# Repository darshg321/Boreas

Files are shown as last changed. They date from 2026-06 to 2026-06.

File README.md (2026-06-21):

# Boreas

a flight controller for a rocket.

made this project to both learn how to make flight controllers in general for my drone. making it i got some more practice in routing pcbs and how to read datasheets!
the plan for this board is to be used in a rocket im going to make, where hopefully with the gyro and motor pins i can get it to 1km altitude or higher. little ambitious for my first rocket project but i tihnk it should be fine! for its kind of a big pcb so it'll be hard to fit on the rocket but itll work fine i think. also the sd card will be useful to gain cool telemetry, and i plan to use it to generate interesting graphs that can tell me how to improve the rocket further.

it uses an STM32F7 as an mcu, connected to an imu, barometer, and magnometer. it also has 3 leds, two buttons, a buzzer, and 3 servo motor pins. it can also charge lipo batteries through usb-c! lastly it has an sd card reader for data display!

## Poster (Zine)
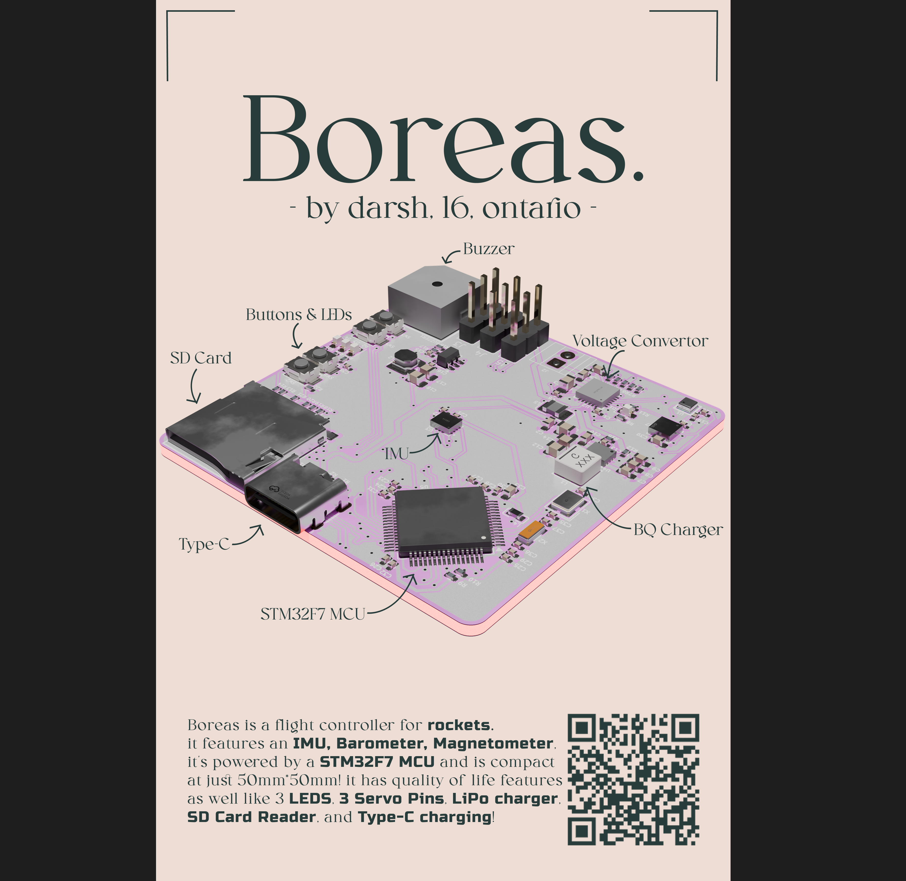
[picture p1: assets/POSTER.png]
poster


## Render
render

## Schematic
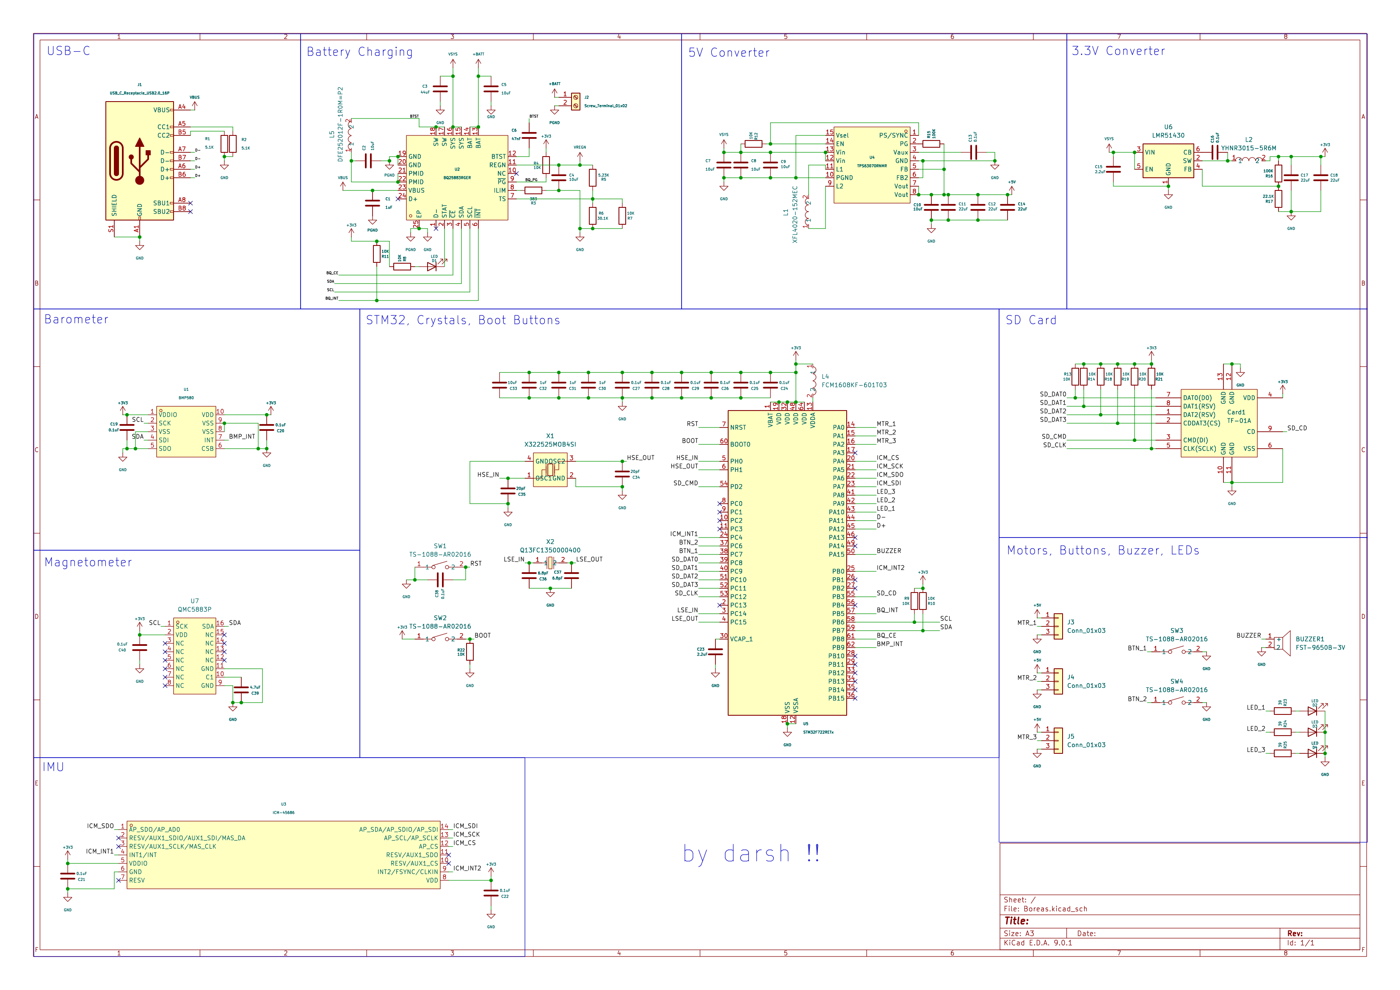
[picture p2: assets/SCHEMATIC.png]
schem


## PCB
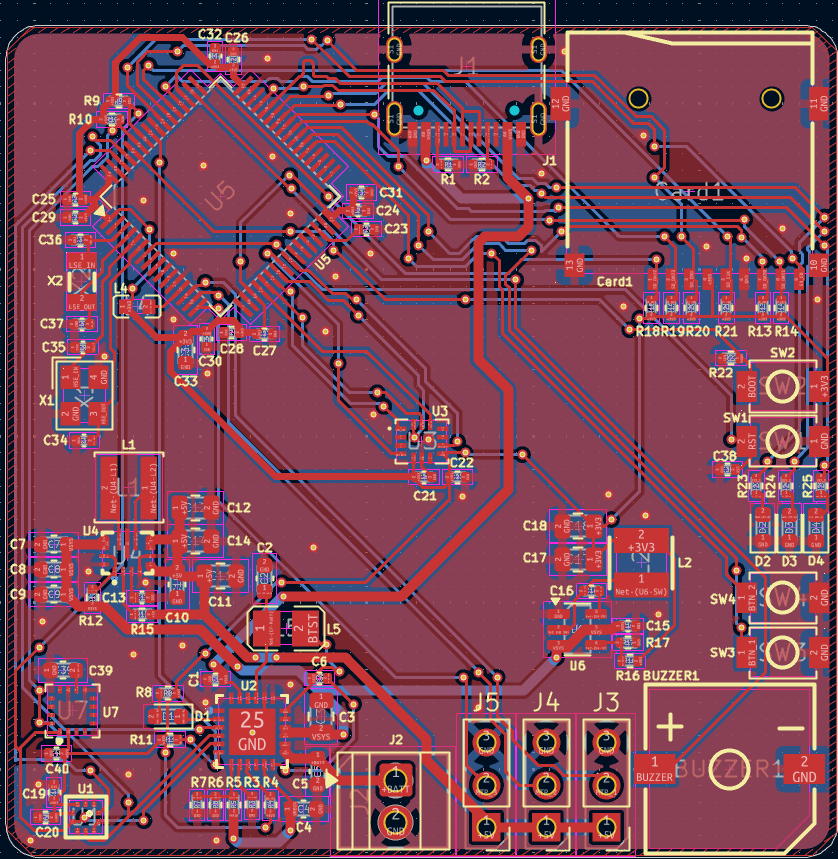
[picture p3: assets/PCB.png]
pcb


## To use

1. plug assembled PCB into computer
2. run ```make flash``` in firmware path after pressing boot and reset buttons to enter flashing mode on the STM32

## BOM

|Item |Price (USD)|
|---|---|
|PCB |2 |
|PCBA |198.65 |
|Shipping|26.51 |
| | |
|Total |227.16 |

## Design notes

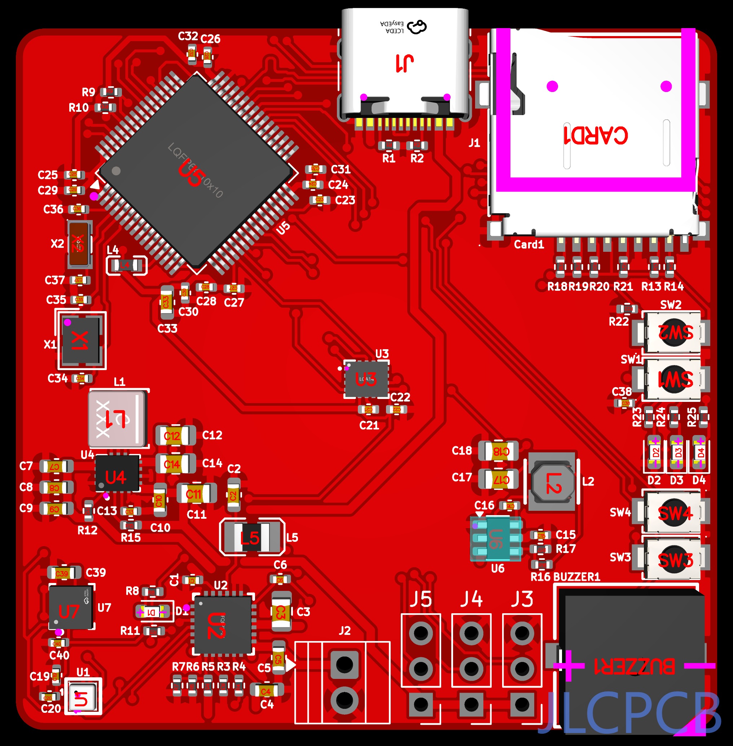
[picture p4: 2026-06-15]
assets/PCB_JLC.png

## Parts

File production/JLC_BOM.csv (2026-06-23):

JLCPCB BOM Tool - BOM Matching
BOM name：production_bom-JLCPCB Assembly Order.xlsx |  |  | Download Time：2026-06-12 11:30:08 |  |  |  | * Our matching results are updated in real-time, but stock and prices may change. If it's been over 24 hours, please re-match before placing your order.
PCB Assembled Qty：5 |  |  | Est. Total Price：69.0311
Your BOM |  |  |  |  | Matched Parts |  |  |  |  |  |  | Order Information
Top Designator | Bottom Designator | Comment | Footprint | JLCPCB Part # | Matches | Part # | Manufacturer | Footprint | Description | Category | Warning | JLCPCB Part # | Product link | Lib Type | Qty | Source | Total Price ($)
BUZZER1 |  | FST-9650B-3V | BUZ-SMD_L9.6-W9.6-LS10.0-R |  | Select by System | FUET-9650B-3V | FUET | SMD,9.6x9.6mm | -20℃~+80℃ 2V~5V 30mA 3V 3kHz 5.5mm 85dB 9.6mm 9.6mm Active Buzzer (Built-in Driving Circuit) Electromagnetic SMD,9.6x9.6mm Buzzers ROHS | Buzzers |  | C391032 | https://jlcpcb.com/partdetail/FUET-FUET_9650B3V/C391032 | Extended | 2 | 2 JLCPCB | 1.1802
C1,C30,C31,C32 |  | 1uF | 402 |  | Select by System | CL05A105KA5NQNC | Samsung Electro-Mechanics | 402 | 1uF 25V X5R ±10% 0402 Multilayer Ceramic Capacitors MLCC - SMD/SMT ROHS | Multilayer Ceramic Capacitors MLCC - SMD/SMT |  | C52923 | https://jlcpcb.com/partdetail/53938-CL05A105KA5NQNC/C52923 | Basic | 20 | 20 JLCPCB | 0.138
C3 |  | 44uF | 805 |  | Select by Customer | CL21A476MQYNNNE | Samsung Electro-Mechanics | 805 | 47uF 6.3V X5R ±20% 0805 Multilayer Ceramic Capacitors MLCC - SMD/SMT ROHS | Multilayer Ceramic Capacitors MLCC - SMD/SMT |  | C16780 | https://jlcpcb.com/partdetail/17464-CL21A476MQYNNNE/C16780 | Basic | 8 | 8 JLCPCB | 1.0848
C6 |  | 47nF | 402 |  | Select by Customer | 0402B473K500NT | FH (Guangdong Fenghua Advanced Tech) | 402 | 47nF 50V X7R ±10% 0402 Multilayer Ceramic Capacitors MLCC - SMD/SMT ROHS | Multilayer Ceramic Capacitors MLCC - SMD/SMT |  | C82219 | https://jlcpcb.com/partdetail/83376-0402B473K500NT/C82219 | Extended | 20 | 20 JLCPCB | 0.068
C10,C2,C33,C4,C5,C7,C8,C9 |  | 10uF | 603 |  | Select by System | CL10A106KP8NNNC | Samsung Electro-Mechanics | 603 | 10V 10uF X5R ±10% 0603 Multilayer Ceramic Capacitors MLCC - SMD/SMT ROHS | Multilayer Ceramic Capacitors MLCC - SMD/SMT |  | C19702 | https://jlcpcb.com/partdetail/20411-CL10A106KP8NNNC/C19702 | Basic | 26 | 26 JLCPCB | 0.4498
C11,C12,C14,C17,C18 |  | 22uF | 805 |  | Select by System | CL21A226MAQNNNE | Samsung Electro-Mechanics | 805 | 22uF 25V X5R ±20% 0805 Multilayer Ceramic Capacitors MLCC - SMD/SMT ROHS | Multilayer Ceramic Capacitors MLCC - SMD/SMT |  | C45783 | https://jlcpcb.com/partdetail/46786-CL21A226MAQNNNE/C45783 | Basic | 18 | 18 JLCPCB | 1.7082
C13,C16,C19,C20,C21,C22,C24,C25,C26,C27,C28,C29,C38,C40 |  | 0.1uF | 402 |  | Unconfirmed | CL05B104KO5NNNC | Samsung Electro-Mechanics | 402 | 100nF 16V X7R ±10% 0402 Multilayer Ceramic Capacitors MLCC - SMD/SMT ROHS | Multilayer Ceramic Capacitors MLCC - SMD/SMT | 1.The comment (CL05B104KO5NNNC) of this part does not match the one (0.1uF) provided in your BOM. Please confirm; | C1525 | https://jlcpcb.com/partdetail/1877-CL05B104KO5NNNC/C1525 | Basic | 38 | 38 JLCPCB | 0.0874
C15,C23 |  | 2.2uF | 402 |  | Select by System | CL05A225MQ5NSNC | Samsung Electro-Mechanics | 402 | 2.2uF 6.3V X5R ±20% 0402 Multilayer Ceramic Capacitors MLCC - SMD/SMT ROHS | Multilayer Ceramic Capacitors MLCC - SMD/SMT |  | C12530 | https://jlcpcb.com/partdetail/13164-CL05A225MQ5NSNC/C12530 | Basic | 20 | 20 JLCPCB | 0.154
C34,C35 |  | 20pF | 402 |  | Select by System | 0402CG200J500NT | FH (Guangdong Fenghua Advanced Tech) | 402 | 20pF 50V C0G ±5% 0402 Multilayer Ceramic Capacitors MLCC - SMD/SMT ROHS | Multilayer Ceramic Capacitors MLCC - SMD/SMT |  | C1554 | https://jlcpcb.com/partdetail/1906-0402CG200J500NT/C1554 | Basic | 20 | 20 JLCPCB | 0.042
C36,C37 |  | 6.8pF | 402 |  | Select by Customer | 0402CG6R8C500NT | FH (Guangdong Fenghua Advanced Tech) | 402 | 50V 6.8pF C0G 0402 Multilayer Ceramic Capacitors MLCC - SMD/SMT ROHS | Multilayer Ceramic Capacitors MLCC - SMD/SMT |  | C1576 | https://jlcpcb.com/partdetail/1928-0402CG6R8C500NT/C1576 | Extended | 20 | 20 JLCPCB | 0.048
C39 |  | 4.7uF | 603 |  | Select by System | CL10A475KO8NNNC | Samsung Electro-Mechanics | 603 | 16V 4.7uF X5R ±10% 0603 Multilayer Ceramic Capacitors MLCC - SMD/SMT ROHS | Multilayer Ceramic Capacitors MLCC - SMD/SMT |  | C19666 | https://jlcpcb.com/partdetail/20375-CL10A475KO8NNNC/C19666 | Basic | 20 | 20 JLCPCB | 0.368
CARD1 |  | TF-01A | TF-SMD_TF-01A |  | Select by System | TF-01A | Korean Hroparts Elec | SMD | 1.85mm Connector and Ejector MicroSD Card (TF Card) Push-Push With Locating Pins SMD SD Card / Memory Card Connector ROHS | SD Card / Memory Card Connector |  | C91145 | https://jlcpcb.com/partdetail/Korean_HropartsElec-TF01A/C91145 | Extended | 2 | 2 JLCPCB | 0.3806
D1,D2,D3,D4 |  | LED | 603 |  | Select by Customer | KT-0603G | Hubei KENTO Elec | 603 | -40℃~+85℃ 1.6mm x 0.8mm square LED 100mW 120° 3.1V 430mcd 513nm~528nm 525nm 5mA Discrete Diode Emerald Green Water Clear 0603 LED Indication - Discrete ROHS | LED Indication - Discrete | 1.The comment (KT-0603G) of this part does not match the one (LED) provided in your BOM. Please confirm; | C12624 | https://jlcpcb.com/partdetail/Hubei_KENTOElec-KT0603G/C12624 | Extended | 20 | 20 JLCPCB | 0.242
J1 |  | USB_C_Receptacle_USB2.0_16P | USB_C_Receptacle_HRO_TYPE-C-31-M-12 |  | Select by Customer | TYPE-C-31-M-12 | Korean Hroparts Elec | SMD | -30℃~+80℃ 1 10,000 cycles 16P 20V 5A 7.35mm Female Surface Mount, Right Angle Type-C SMD USB Connectors ROHS | USB Connectors |  | C165948 | https://jlcpcb.com/partdetail/Korean_HropartsElec-TYPE_C_31_M12/C165948 | Extended | 2 | 2 JLCPCB | 0.3684
L1 |  | XFL4020-152MEC | IND-SMD_L4.0-W4.0-A |  | Select by System | XFL4020-152MEC | Coilcraft | SMD,4x4mm | 1.5uH 14.4mΩ 4.6A 9.1A Magnetic Shielded Inductor ±20% SMD,4x4mm Power Inductors ROHS | Power Inductors |  | C3033018 | https://jlcpcb.com/partdetail/Coilcraft-XFL4020152MEC/C3033018 | Extended | 2 | 2 JLCPCB | 2.7506
L2 |  | YHNR3015-5R6M | IND-SMD_L3.0-W3.0 |  | Select by System | YHNR3015-5R6M | YJYCOIN | SMD,3x3mm | 2.2A 250mΩ 5.6uH Magnetic Shielded Inductor ±20% SMD,3x3mm Power Inductors ROHS |  |  | C18236327 | https://jlcpcb.com/partdetail/YJYCOIN-YHNR30155R6M/C18236327 | Extended | 15 | 15 JLCPCB | 1.1235
L4 |  | FCM1608KF-601T03 | L0603 |  | Select by Customer | BLM18EG601SN1D | Murata Electronics | 603 | -55℃~+125℃ 1 350mΩ 500mA 600Ω@100MHz ±25% 0603 Ferrite Beads ROHS | Ferrite Beads |  | C20345 | https://jlcpcb.com/partdetail/MurataElectronics-BLM18EG601SN1D/C20345 | Extended | 10 | 10 JLCPCB | 0.81
L5 |  | DFE252012F-1R0M=P2 | L2520 |  | Select by System | DFE252012F-1R0M=P2 | Murata Electronics | 1008 | 1uH 3.3A 4.7A 40mΩ ±20% 1008 Power Inductors ROHS | Power Inductors |  | C435392 | https://jlcpcb.com/partdetail/MurataElectronics-DFE252012F_1R0MP2/C435392 | Extended | 5 | 5 JLCPCB | 0.909
R1,R2 |  | 5.1K | 402 |  | Unconfirmed | 0402WGF5101TCE | UNI-ROYAL(Uniroyal Elec) | 402 | -55℃~+155℃ 5.1kΩ 50V 62.5mW Thick Film Resistor ±1% ±100ppm/℃ 0402 Chip Resistor - Surface Mount ROHS | Chip Resistor - Surface Mount | 1.The comment (0402WGF5101TCE) of this part does not match the one (5.1K) provided in your BOM. Please confirm; | C25905 | https://jlcpcb.com/partdetail/26648-0402WGF5101TCE/C25905 | Basic | 20 | 20 JLCPCB | 0.018
R3 |  | 383 | 402 |  | Select by Customer | RTT023830FTH | RALEC | 402 | -55℃~+155℃ 383Ω 50V 62.5mW Thick Film Resistor ±1% ±100ppm/℃ 0402 Chip Resistor - Surface Mount ROHS | Chip Resistor - Surface Mount | 1.The comment (RTT023830FTH) of this part does not match the one (383) provided in your BOM. Please confirm; | C112940 | https://jlcpcb.com/partdetail/RALEC-RTT023830FTH/C112940 | Extended | 20 | 20 JLCPCB | 0.012
R5 |  | 5.23K | 402 |  | Unconfirmed | FRC0402F5231TS | FOJAN | 402 | -55℃~+155℃ 5.23kΩ 50V 62.5mW Thick Film Resistor ±1% ±100ppm/℃ 0402 Chip Resistor - Surface Mount ROHS | Chip Resistor - Surface Mount | 1.The comment (FRC0402F5231TS) of this part does not match the one (5.23K) provided in your BOM. Please confirm; | C2933105 | https://jlcpcb.com/partdetail/FOJAN-FRC0402F5231TS/C2933105 | Extended | 20 | 20 JLCPCB | 0.018
R6 |  | 30.1K | 402 |  | Unconfirmed | 0402WGF3012TCE | UNI-ROYAL(Uniroyal Elec) | 402 | -55℃~+155℃ 30.1kΩ 50V 62.5mW Thick Film Resistor ±1% ±100ppm/℃ 0402 Chip Resistor - Surface Mount ROHS | Chip Resistor - Surface Mount | 1.The comment (0402WGF3012TCE) of this part does not match the one (30.1K) provided in your BOM. Please confirm; | C29402 | https://jlcpcb.com/partdetail/30156-0402WGF3012TCE/C29402 | Extended | 20 | 20 JLCPCB | 0.02
R10,R11,R12,R13,R14,R18,R19,R20,R21,R22,R4,R7,R8,R9 |  | 10K | 402 |  | Unconfirmed | 0402WGF1002TCE | UNI-ROYAL(Uniroyal Elec) | 402 | -55℃~+155℃ 10kΩ 50V 62.5mW Thick Film Resistor ±1% ±100ppm/℃ 0402 Chip Resistor - Surface Mount ROHS | Chip Resistor - Surface Mount | 1.The comment (0402WGF1002TCE) of this part does not match the one (10K) provided in your BOM. Please confirm; | C25744 | https://jlcpcb.com/partdetail/26487-0402WGF1002TCE/C25744 | Basic | 38 | 38 JLCPCB | 0.1064
R15,R16 |  | 100K | 402 |  | Unconfirmed | 0402WGF1003TCE | UNI-ROYAL(Uniroyal Elec) | 402 | -55℃~+155℃ 100kΩ 50V 62.5mW Thick Film Resistor ±1% ±100ppm/℃ 0402 Chip Resistor - Surface Mount ROHS | Chip Resistor - Surface Mount | 1.The comment (0402WGF1003TCE) of this part does not match the one (100K) provided in your BOM. Please confirm; | C25741 | https://jlcpcb.com/partdetail/26484-0402WGF1003TCE/C25741 | Basic | 20 | 20 JLCPCB | 0.02
R17 |  | 22.1K | 402 |  | Unconfirmed | 0402WGF2212TCE | UNI-ROYAL(Uniroyal Elec) | 402 | -55℃~+155℃ 22.1kΩ 50V 62.5mW Thick Film Resistor ±1% ±100ppm/℃ 0402 Chip Resistor - Surface Mount ROHS | Chip Resistor - Surface Mount | 1.The comment (0402WGF2212TCE) of this part does not match the one (22.1K) provided in your BOM. Please confirm; | C43473 | https://jlcpcb.com/partdetail/44464-0402WGF2212TCE/C43473 | Extended | 20 | 20 JLCPCB | 0.016
R23,R24,R25 |  | 39 | 402 |  | Unconfirmed | RCT0239RJLF | HKR(Hong Kong Resistors) | 402 | -55℃~+155℃ 39Ω 50V 62.5mW Thick Film Resistor ±200ppm/℃ ±5% 0402 Chip Resistor - Surface Mount ROHS | Chip Resistor - Surface Mount | 1.The comment (RCT0239RJLF) of this part does not match the one (39) provided in your BOM. Please confirm; | C174212 | https://jlcpcb.com/partdetail/HKR_Hong_Kong_Resistors-RCT0239RJLF/C174212 | Extended | 20 | 20 JLCPCB | 0.016
SW1,SW2,SW3,SW4 |  | TS-1088-AR02016 | SW-SMD_L3.9-W3.0-P4.45 |  | Select by System | TS-1088-AR02016 | XUNPU | SMD,4x3mm | -30℃~+80℃ 1.6N 100,000 cycles 12V 2mm 3mm 4mm 50mA Black Round Button SMD(SMT) Tab SPST Surface Mount,Vertical Without Bracket SMD,4x3mm Tactile Switches ROHS | Tactile Switches |  | C720477 | https://jlcpcb.com/partdetail/XUNPU-TS_1088AR02016/C720477 | Basic | 12 | 12 JLCPCB | 0.6624
U1 |  | BMP580 | LGA-10_L2.0-W2.0-P0.50-TL_BMP580 |  | Select by System | BMP580 | Bosch Sensortec | LGA-10(2x2) | -40℃~+85℃ 0.5pa/K 1.73V~3.6V 30Kpa~1.25bar 5.5uA 6pa 75pa I2C、SPI、I3C LGA-10(2x2) Pressure Sensors ROHS | Pressure Sensors |  | C22391138 | https://jlcpcb.com/partdetail/BoschSensortec-BMP580/C22391138 | Extended | 2 | 2 JLCPCB | 2.67
U2 |  | BQ25883RGER | VFQFPN-24_L4.0-W4.0-P0.50-BL-EP2.8 |  | Select by System | BQ25883RGER | Texas Instruments | VQFN-24-EP(4x4) | -40℃~+85℃ 12uA 2 2.2A 3.9V~6.2V 8.4V Charging IC I2C Lithium Battery Support Support VQFN-24-EP(4x4) Battery Management ROHS | Battery Management |  | C544362 | https://jlcpcb.com/partdetail/TexasInstruments-BQ25883RGER/C544362 | Extended | 2 | 2 JLCPCB | 6.4362
U3 |  | ICM-45686 | LGA-14_L3.0-W2.5-P0.50-TL |  | Select by System | ICM-45686 | TDK InvenSense | LGA-14(3x2.5) | LGA-14(3x2.5) Accelerometers ROHS | Accelerometers |  | C22459454 | https://jlcpcb.com/partdetail/TDKInvenSense-ICM45686/C22459454 | Extended | 2 | 2 JLCPCB | 25.8608
U4 |  | TPS63070RNMR | VQFN-15_L3.0-W2.5-P0.50-BL |  | Select by System | TPS63070RNMR | Texas Instruments | VQFN-15-HR(2.5x3) | -40℃~+125℃@(TJ) 1 2.4MHz 2.5V~9V 2A 2V~16V 50uA Adjustable Buck-Boost Buck-Boost Built-in Yes VQFN-15-HR(2.5x3) DC-DC Converters ROHS | DC-DC Converters |  | C109322 | https://jlcpcb.com/partdetail/TexasInstruments-TPS63070RNMR/C109322 | Extended | 2 | 2 JLCPCB | 2.7312
U5 |  | STM32F722RETx | LQFP-64_10x10mm_P0.5mm |  | Select by Customer | STM32F722RET6 | STMicroelectronics | LQFP-64(10x10) | -40℃~+85℃ 1.7V~3.6V 12bit 12bit 216MHz 256KB 32 Bit 50 512KB ARM Cortex-M7 Built-in FLASH LQFP-64(10x10) Microcontrollers (MCU/MPU/SOC) ROHS | Microcontrollers (MCU/MPU/SOC) |  | C118207 | https://jlcpcb.com/partdetail/STMicroelectronics-STM32F722RET6/C118207 | Extended | 2 | 2 JLCPCB | 12.5338
U6 |  | LMR51430 | SOT-23-6 |  | Select by System | LMR51430YFDDCR | Texas Instruments | SOT-23-6-THIN(DDC) | -40℃~+150℃ 1 1.1MHz 3A 4.5V~36V 40uA 600mV~34.2V Adjustable Buck Buck Built-in Yes SOT-23-6-THIN(DDC) DC-DC Converters ROHS | DC-DC Converters |  | C5219261 | https://jlcpcb.com/partdetail/TexasInstruments-LMR51430YFDDCR/C5219261 | Extended | 2 | 2 JLCPCB | 1.6672
U7 |  | QMC5883P | LGA-16_L3.0-W3.0-P0.50-BL_SQ |  | Select by System | QMC5883P | QST | LGA-16(3x3) | -40℃~+85℃ 16bit 2.5V~3.6V 35uA I2C ±3mT ±3mT LGA-16(3x3) 3D Magnetic Sensors ROHS | 3D Magnetic Sensors |  | C2847467 | https://jlcpcb.com/partdetail/QST-QMC5883P/C2847467 | Extended | 2 | 2 JLCPCB | 3.0504
X1 |  | X322525MOB4SI | CRYSTAL-SMD_4P-L3.2-W2.5-BL |  | Select by System | X322525MOB4SI | YXC Crystal Oscillators | SMD3225-4P | -40℃~+85℃ 12pF 25MHz Crystal Oscillator ±10ppm ±20ppm SMD3225-4P Crystals ROHS | Crystals |  | C9006 | https://jlcpcb.com/partdetail/YXC_CrystalOscillators-X322525MOB4SI/C9006 | Basic | 6 | 6 JLCPCB | 0.4452
X2 |  | Q13FC1350000400 | FC-135R_L3.2-W1.5 |  | Select by System | Q13FC13500004 | Seiko Epson | SMD3215-2P | -40℃~+85℃ 12.5pF 32.768kHz 70kΩ Crystal Oscillator ±20ppm SMD3215-2P Crystals ROHS | Crystals |  | C32346 | https://jlcpcb.com/partdetail/SeikoEpson-Q13FC13500004/C32346 | Basic | 5 | 5 JLCPCB | 0.835
J2 |  | Screw_Terminal_01x02 | TerminalBlock_Xinya_XY308-2.54-2P_1x02_P2.54mm_Horizontal |  | No matches | No Part Selected
J3,J4,J5 |  | Conn_01x03 | PinHeader_1x03_P2.54mm_Vertical |  | No matches | No Part Selected |  |  |  |  |  |  |  |  |  | TOTAL | 69.0311

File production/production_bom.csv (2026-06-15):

Designator | Footprint | Quantity | Value | LCSC Part #
BUZZER1 | BUZ-SMD_L9.6-W9.6-LS10.0-R | 1 | FST-9650B-3V | C391032
C1, C30, C31, C32 | 0402 | 4 | 1uF
C10, C2, C33, C4, C5, C7, C8, C9 | 0603 | 8 | 10uF
C11, C12, C14, C17, C18 | 0805 | 5 | 22uF
C13, C16, C19, C20, C21, C22, C24, C25, C26, C27, C28, C29, C38, C40 | 0402 | 14 | 0.1uF
C15, C23 | 0402 | 2 | 2.2uF
C3 | 0805 | 1 | 44uF
C34, C35 | 0402 | 2 | 20pF
C36, C37 | 0402 | 2 | 6.8pF
C39 | 0603 | 1 | 4.7uF
C6 | 0402 | 1 | 47nF
CARD1 | TF-SMD_TF-01A | 1 | TF-01A | C91145
D1, D2, D3, D4 | 0603 | 4 | LED
J1 | USB_C_Receptacle_HRO_TYPE-C-31-M-12 | 1 | USB_C_Receptacle_USB2.0_16P
J2 | TerminalBlock_Xinya_XY308-2.54-2P_1x02_P2.54mm_Horizontal | 1 | Screw_Terminal_01x02
J3, J4, J5 | PinHeader_1x03_P2.54mm_Vertical | 3 | Conn_01x03
L1 | IND-SMD_L4.0-W4.0-A | 1 | XFL4020-152MEC | C3033018
L2 | IND-SMD_L3.0-W3.0 | 1 | YHNR3015-5R6M | C18236327
L4 | L0603 | 1 | FCM1608KF-601T03 | C141723
L5 | L2520 | 1 | DFE252012F-1R0M=P2 | C435392
R1, R2 | 0402 | 2 | 5.1K
R10, R11, R12, R13, R14, R18, R19, R20, R21, R22, R4, R7, R8, R9 | 0402 | 14 | 10K
R15, R16 | 0402 | 2 | 100K
R17 | 0402 | 1 | 22.1K
R23, R24, R25 | 0402 | 3 | 39
R3 | 0402 | 1 | 383
R5 | 0402 | 1 | 5.23K
R6 | 0402 | 1 | 30.1K
SW1, SW2, SW3, SW4 | SW-SMD_L3.9-W3.0-P4.45 | 4 | TS-1088-AR02016 | C720477
U1 | LGA-10_L2.0-W2.0-P0.50-TL_BMP580 | 1 | BMP580 | C22391138
U2 | VFQFPN-24_L4.0-W4.0-P0.50-BL-EP2.8 | 1 | BQ25883RGER | C544362
U3 | LGA-14_L3.0-W2.5-P0.50-TL | 1 | ICM-45686 | C22459454
U4 | VQFN-15_L3.0-W2.5-P0.50-BL | 1 | TPS63070RNMR | C109322
U5 | LQFP-64_10x10mm_P0.5mm | 1 | STM32F722RETx
U6 | SOT-23-6 | 1 | LMR51430
U7 | LGA-16_L3.0-W3.0-P0.50-BL_SQ | 1 | QMC5883P | C2847467
X1 | CRYSTAL-SMD_4P-L3.2-W2.5-BL | 1 | X322525MOB4SI | C9006
X2 | FC-135R_L3.2-W1.5 | 1 | Q13FC1350000400 | C32346

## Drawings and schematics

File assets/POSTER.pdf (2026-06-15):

Boreas.

# - by darsh, 16, ontario -

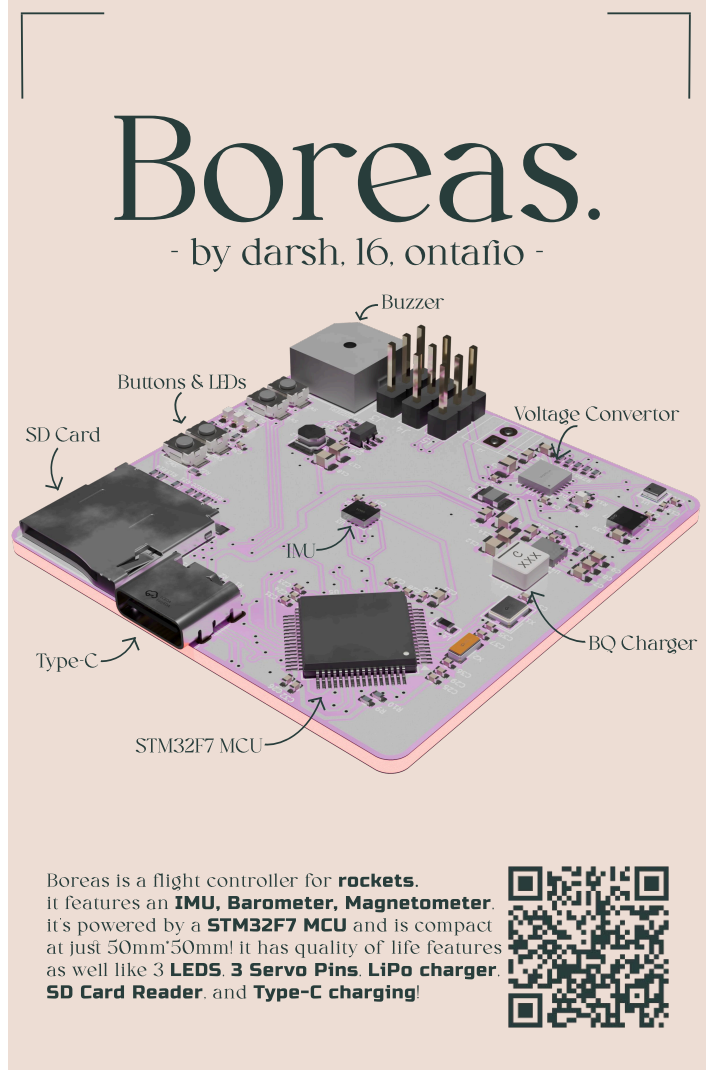
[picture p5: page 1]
Buzzer; Buttons & L EDs; Voltage Convertor; SD Card; IMU; Type-C; BQ Charger; STM32F7 MCU

Boreas is a flight controller for rockets.
it features an IMU, Barometer, Magnetometer,
it’s powered by a STM32F7 MCU and is compact
at just 50mm*50mm! it has quality of life features
as well like 3 LEDS, 3 Servo Pins, LiPo charger,
SD Card Reader, and Type-C charging!

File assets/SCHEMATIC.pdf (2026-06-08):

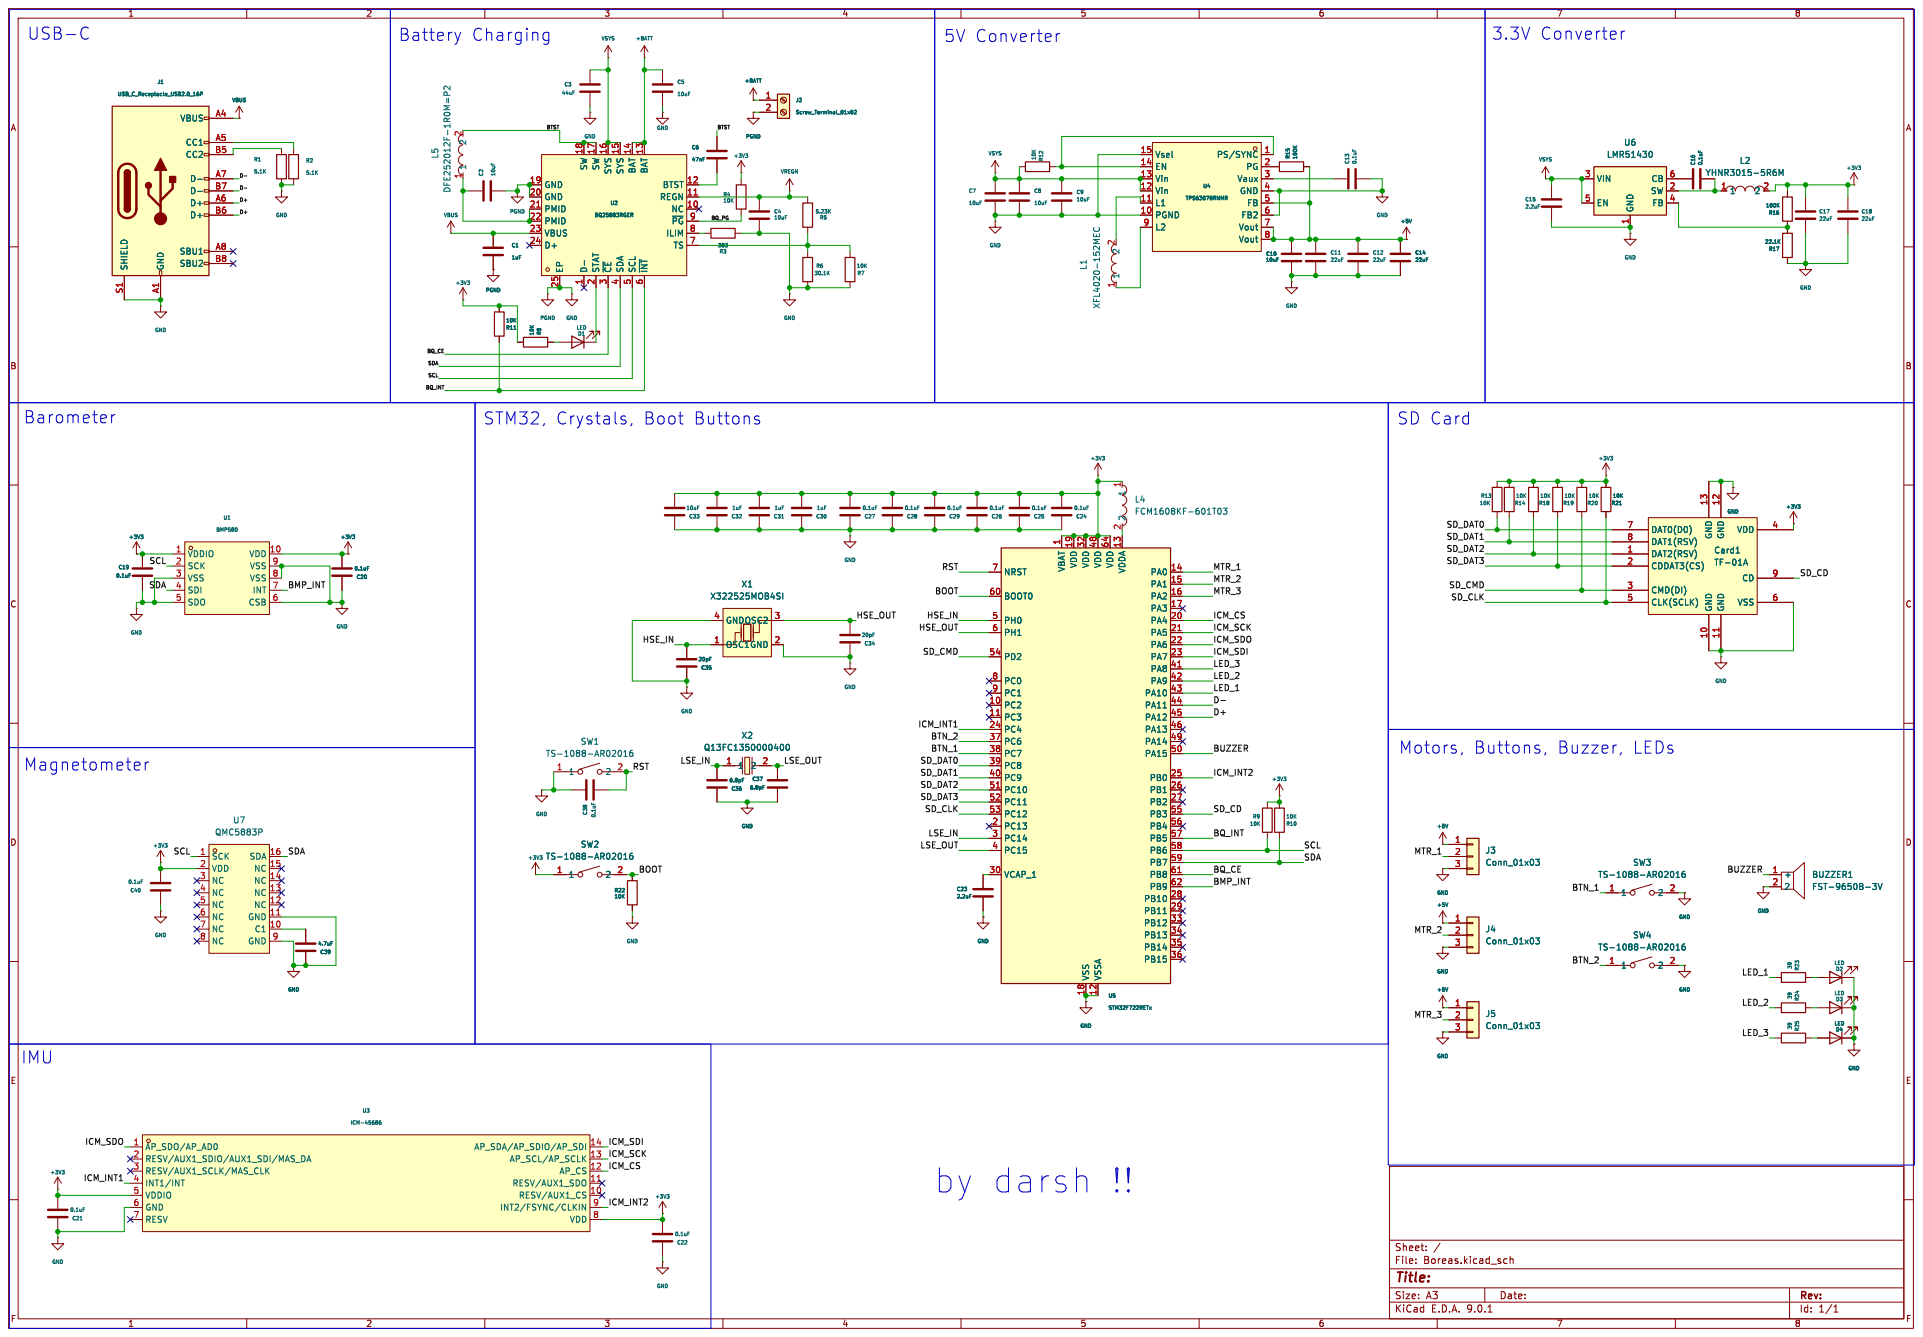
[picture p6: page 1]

5 ~{INT} 6 D+ 24 TS 7 VBUS 23 ILIM 8 PMID 22 ~{PG}9 PMID 21 NC 10 GND 20 REGN 11 GND 19 BTST 12 SW 18 SW 17 SYS 16 SYS 15 BAT 14 BAT 13 10K R8R11

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

PS/SYNC 1 PG 2 Vaux 3 GND 4 FB 5 FB2 6 Vout 7 Vout 8 Vsel 15 EN 14 Vin 13 Vin 12

22uF U4 TPS63070RNMRPS/SYNC 1 PG 2 Vaux 3 GND 4 FB 5 FB2 6 Vout 7 Vout 8 Vsel 15 EN 14 Vin 13 Vin 12

1 VDD 19 VDD 32 VSS 18 VDD 48 VSSA 12 VDD 64 VDDA 13 PA0 14 PA1 15 PA2 16 PA3 17 PA4 20 PA5 21 PA6 22 PA7 23 PA8 41 PA9 42 PA10 43 PA11 44 PA12 45 PA13 46 PA14 49 PA15 50 PB0 25 PB1 26 PB2 27 PB3 55 PB4 56 PB5 57 PB6 58 PB7 59 PB8 61 PB9 62 PB10 28 PB11 29 PB12 33 PB13 34 PB14 35 PB15 36

Motors, Buttons, Buzzer, LEDs

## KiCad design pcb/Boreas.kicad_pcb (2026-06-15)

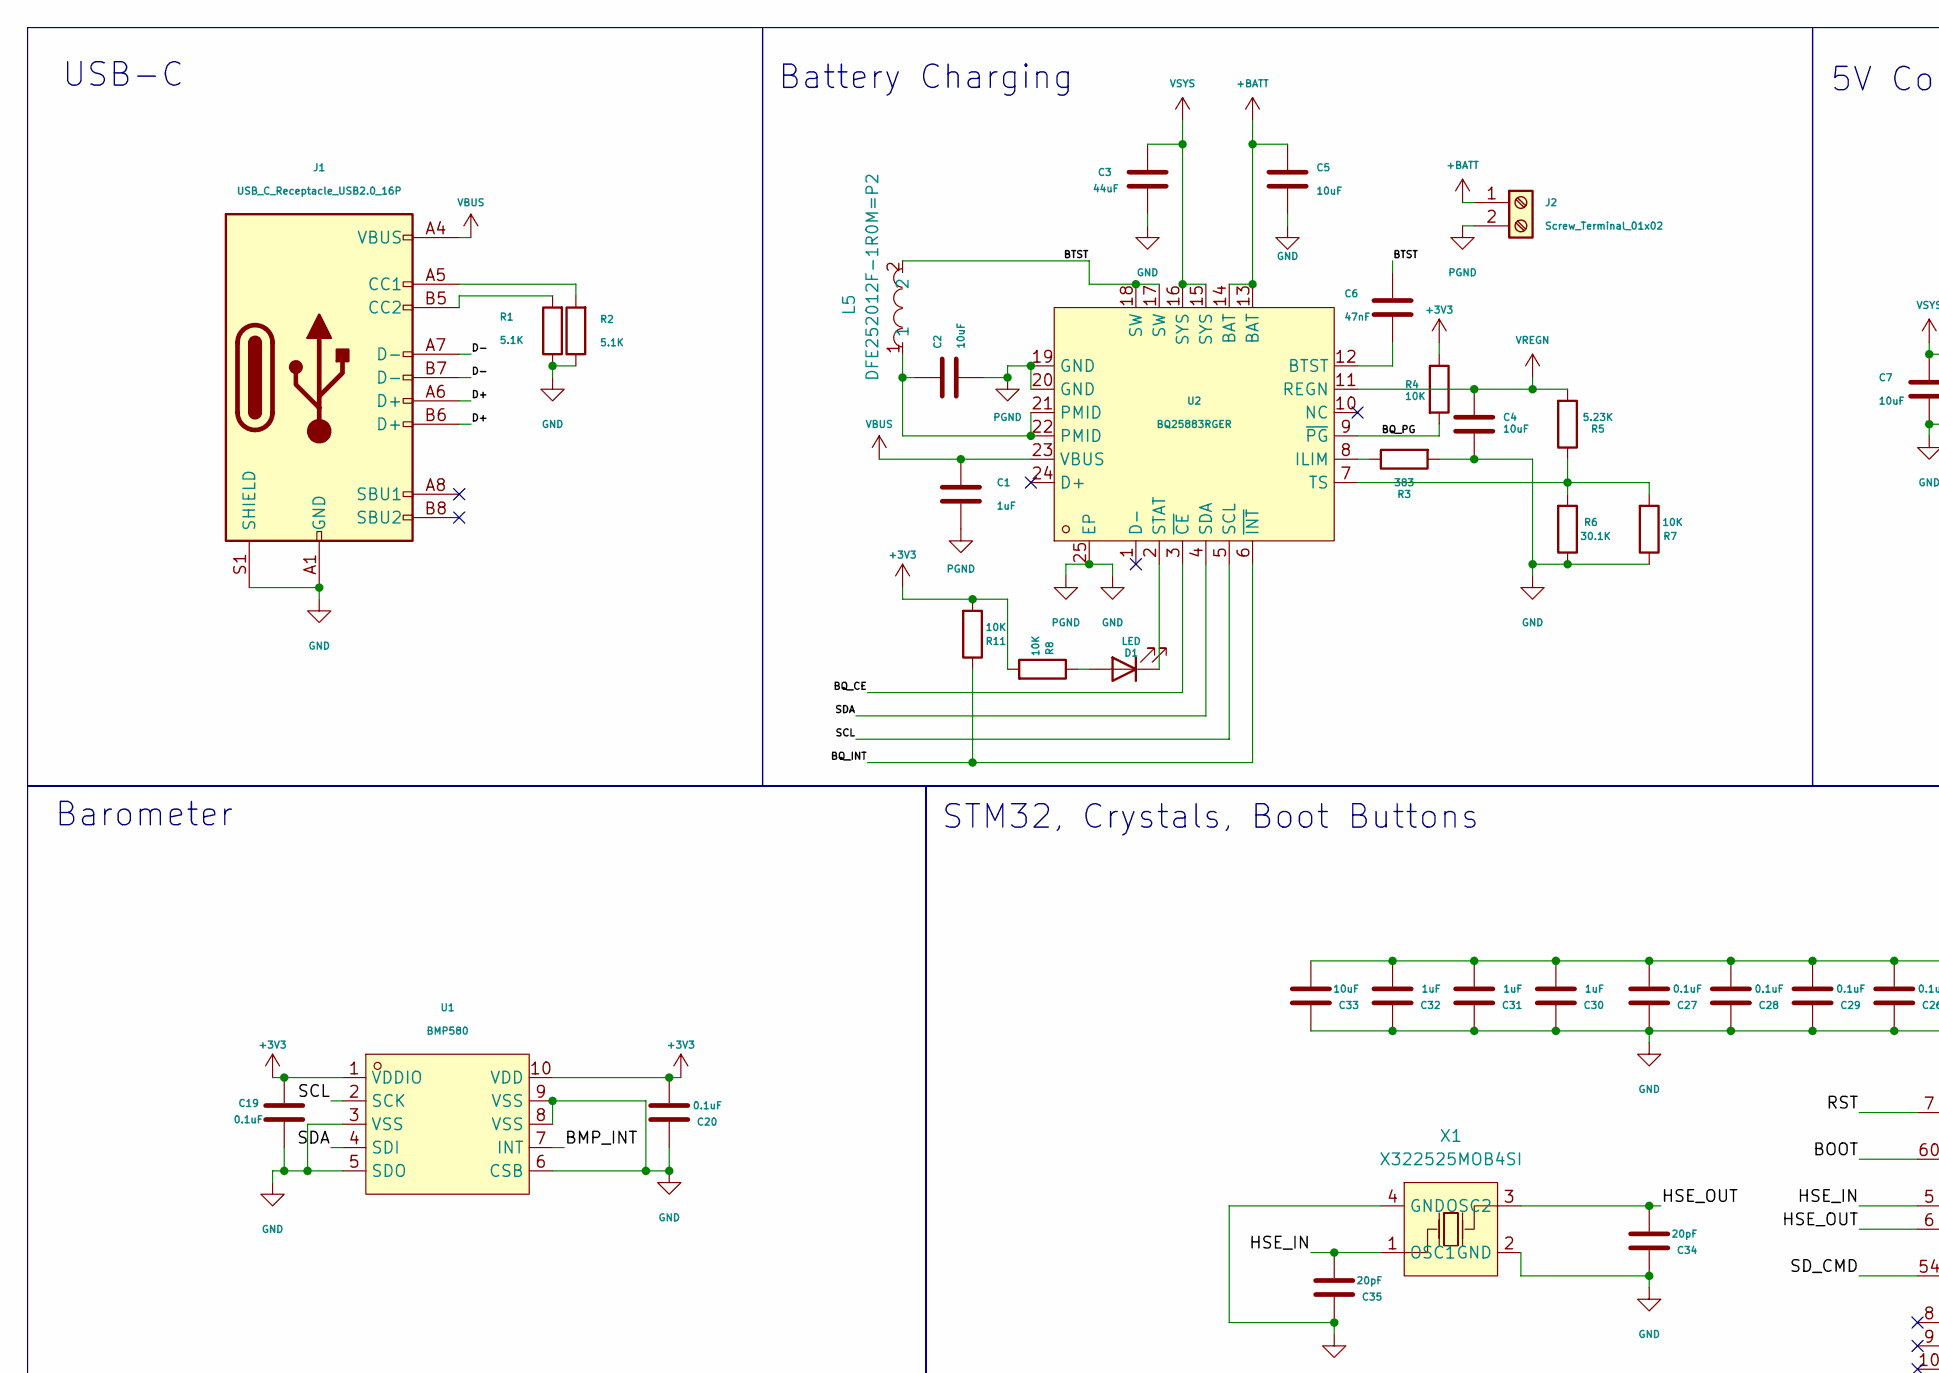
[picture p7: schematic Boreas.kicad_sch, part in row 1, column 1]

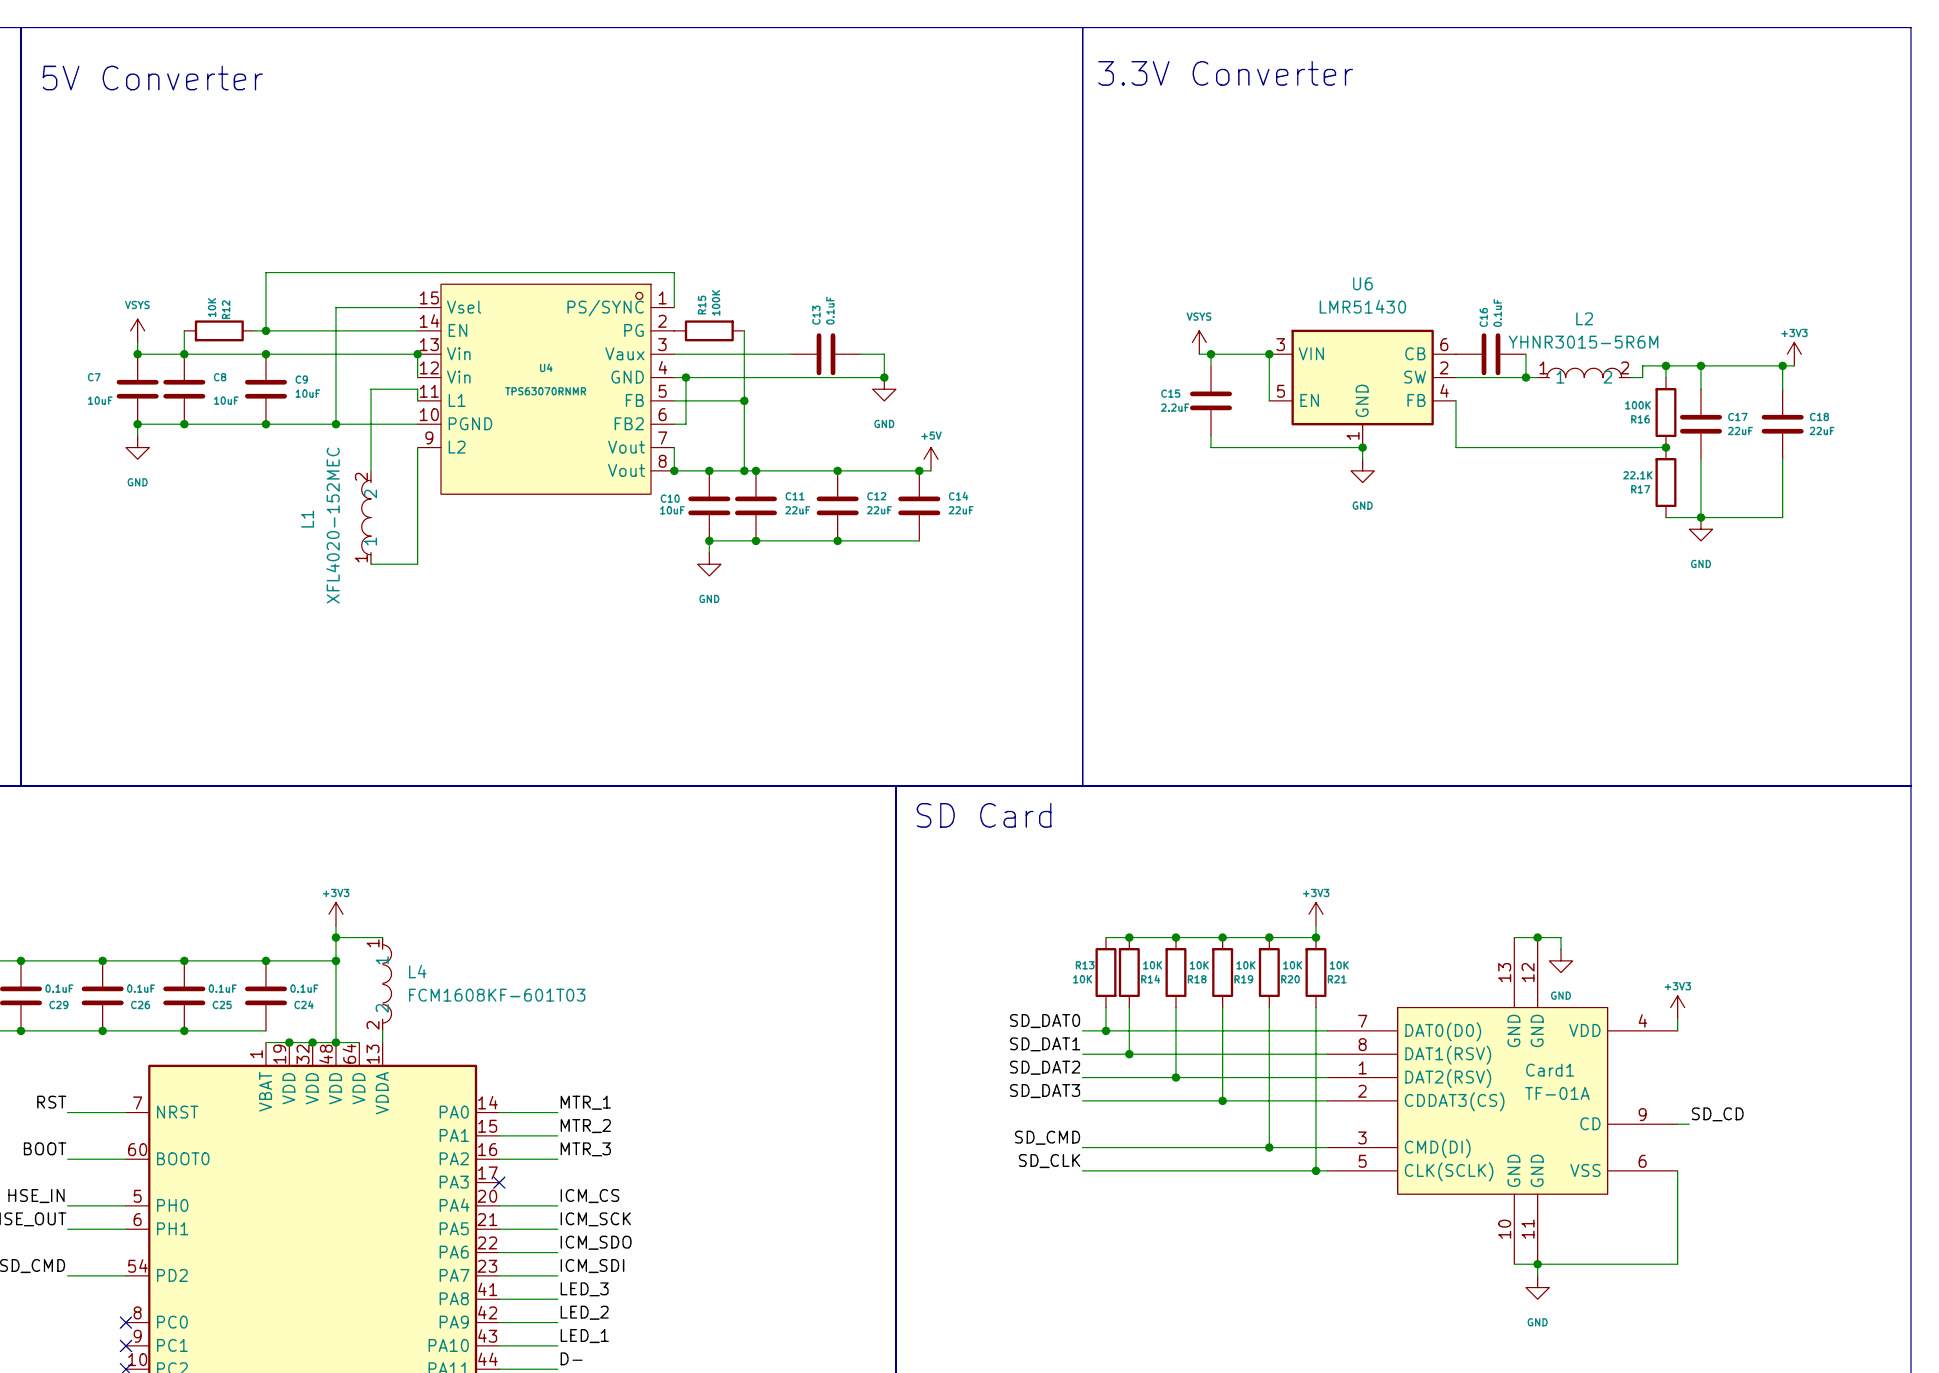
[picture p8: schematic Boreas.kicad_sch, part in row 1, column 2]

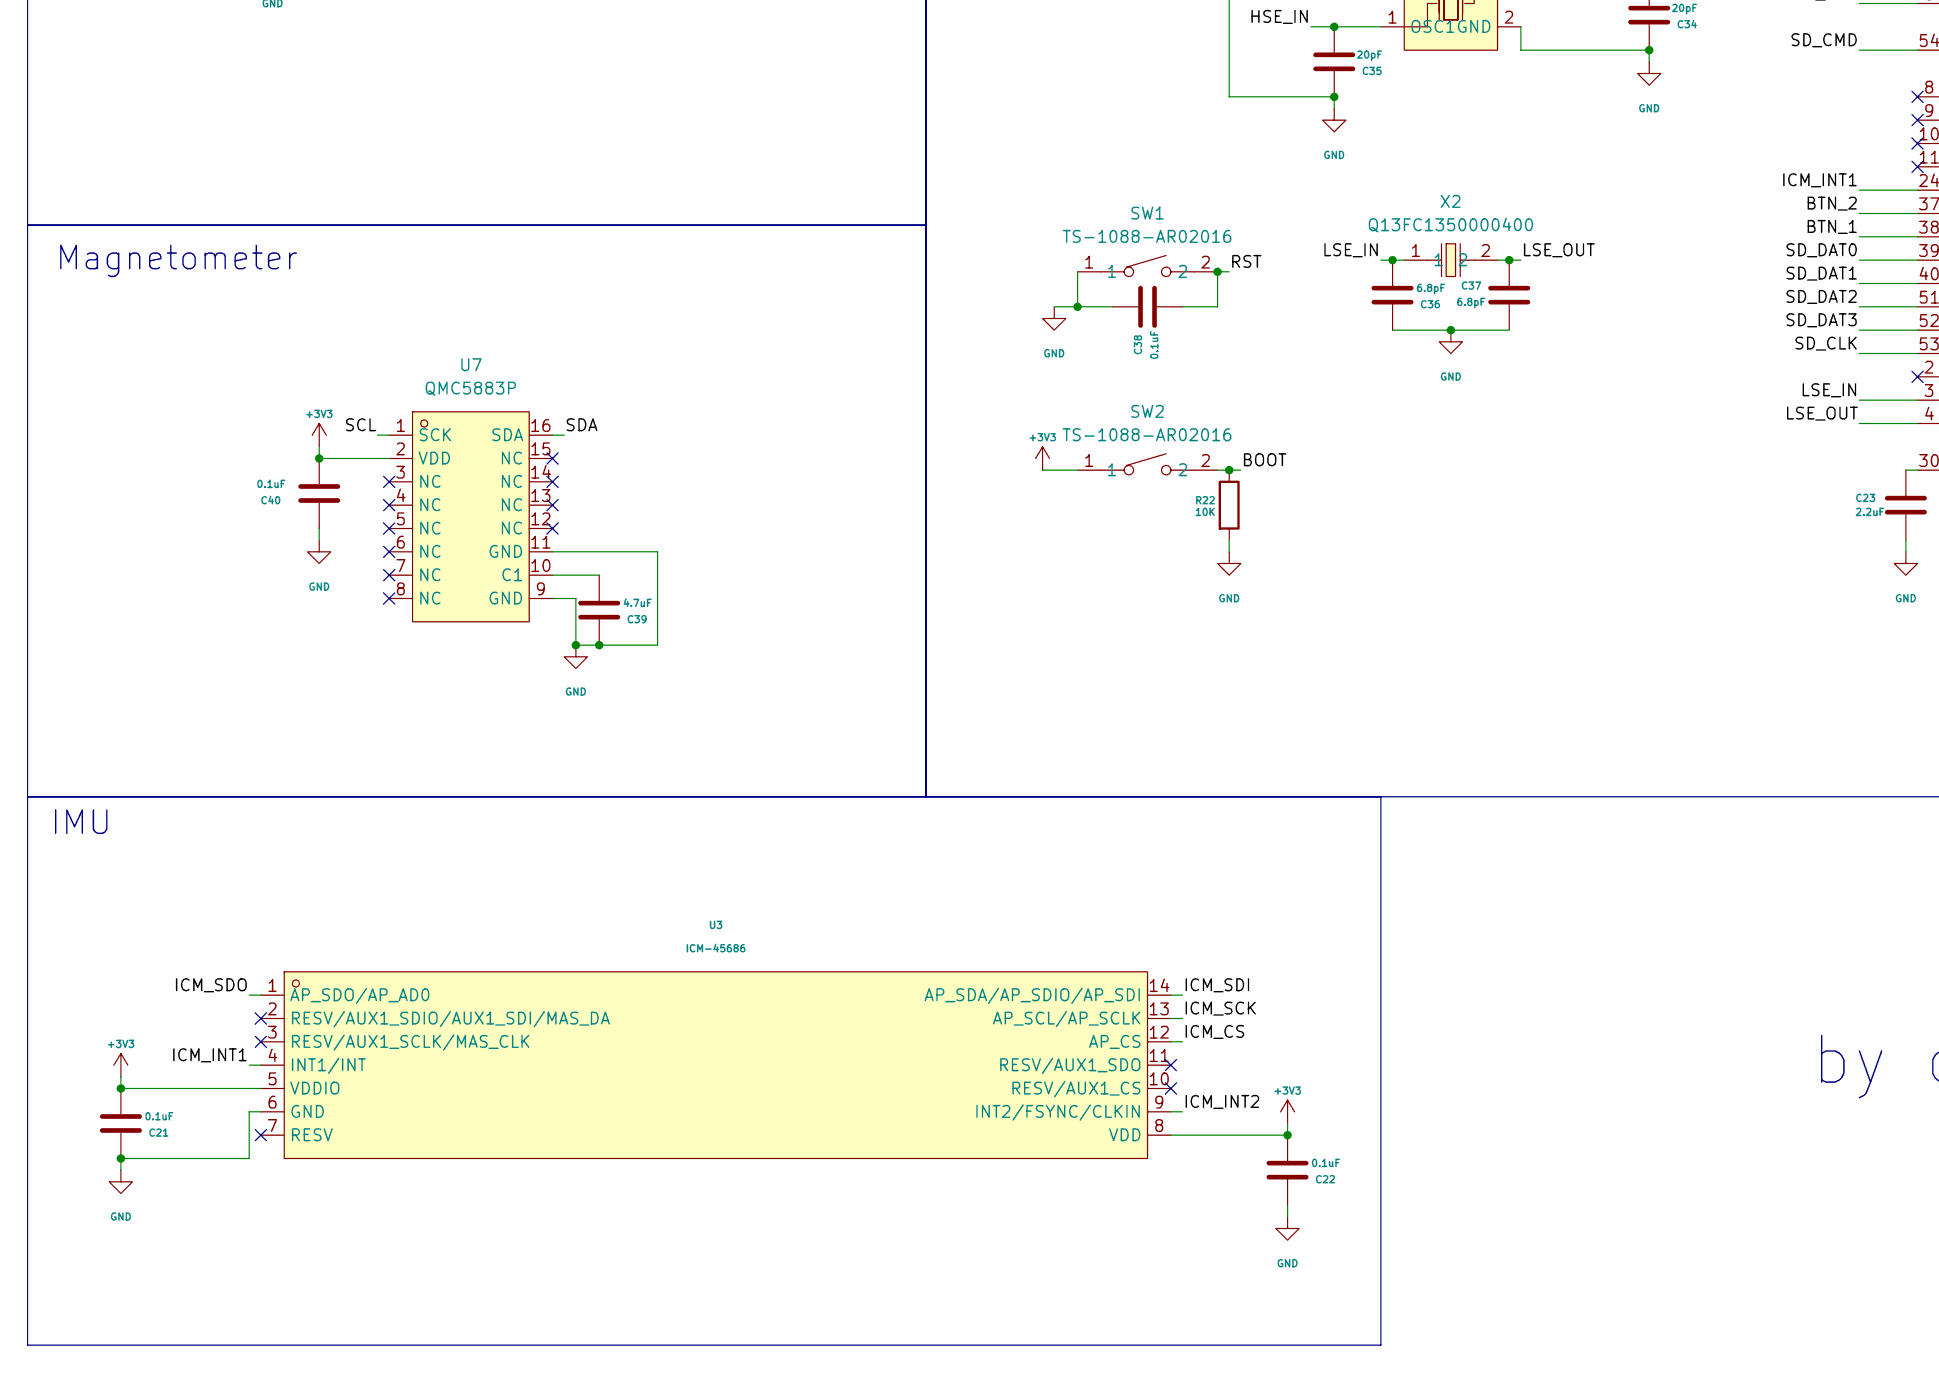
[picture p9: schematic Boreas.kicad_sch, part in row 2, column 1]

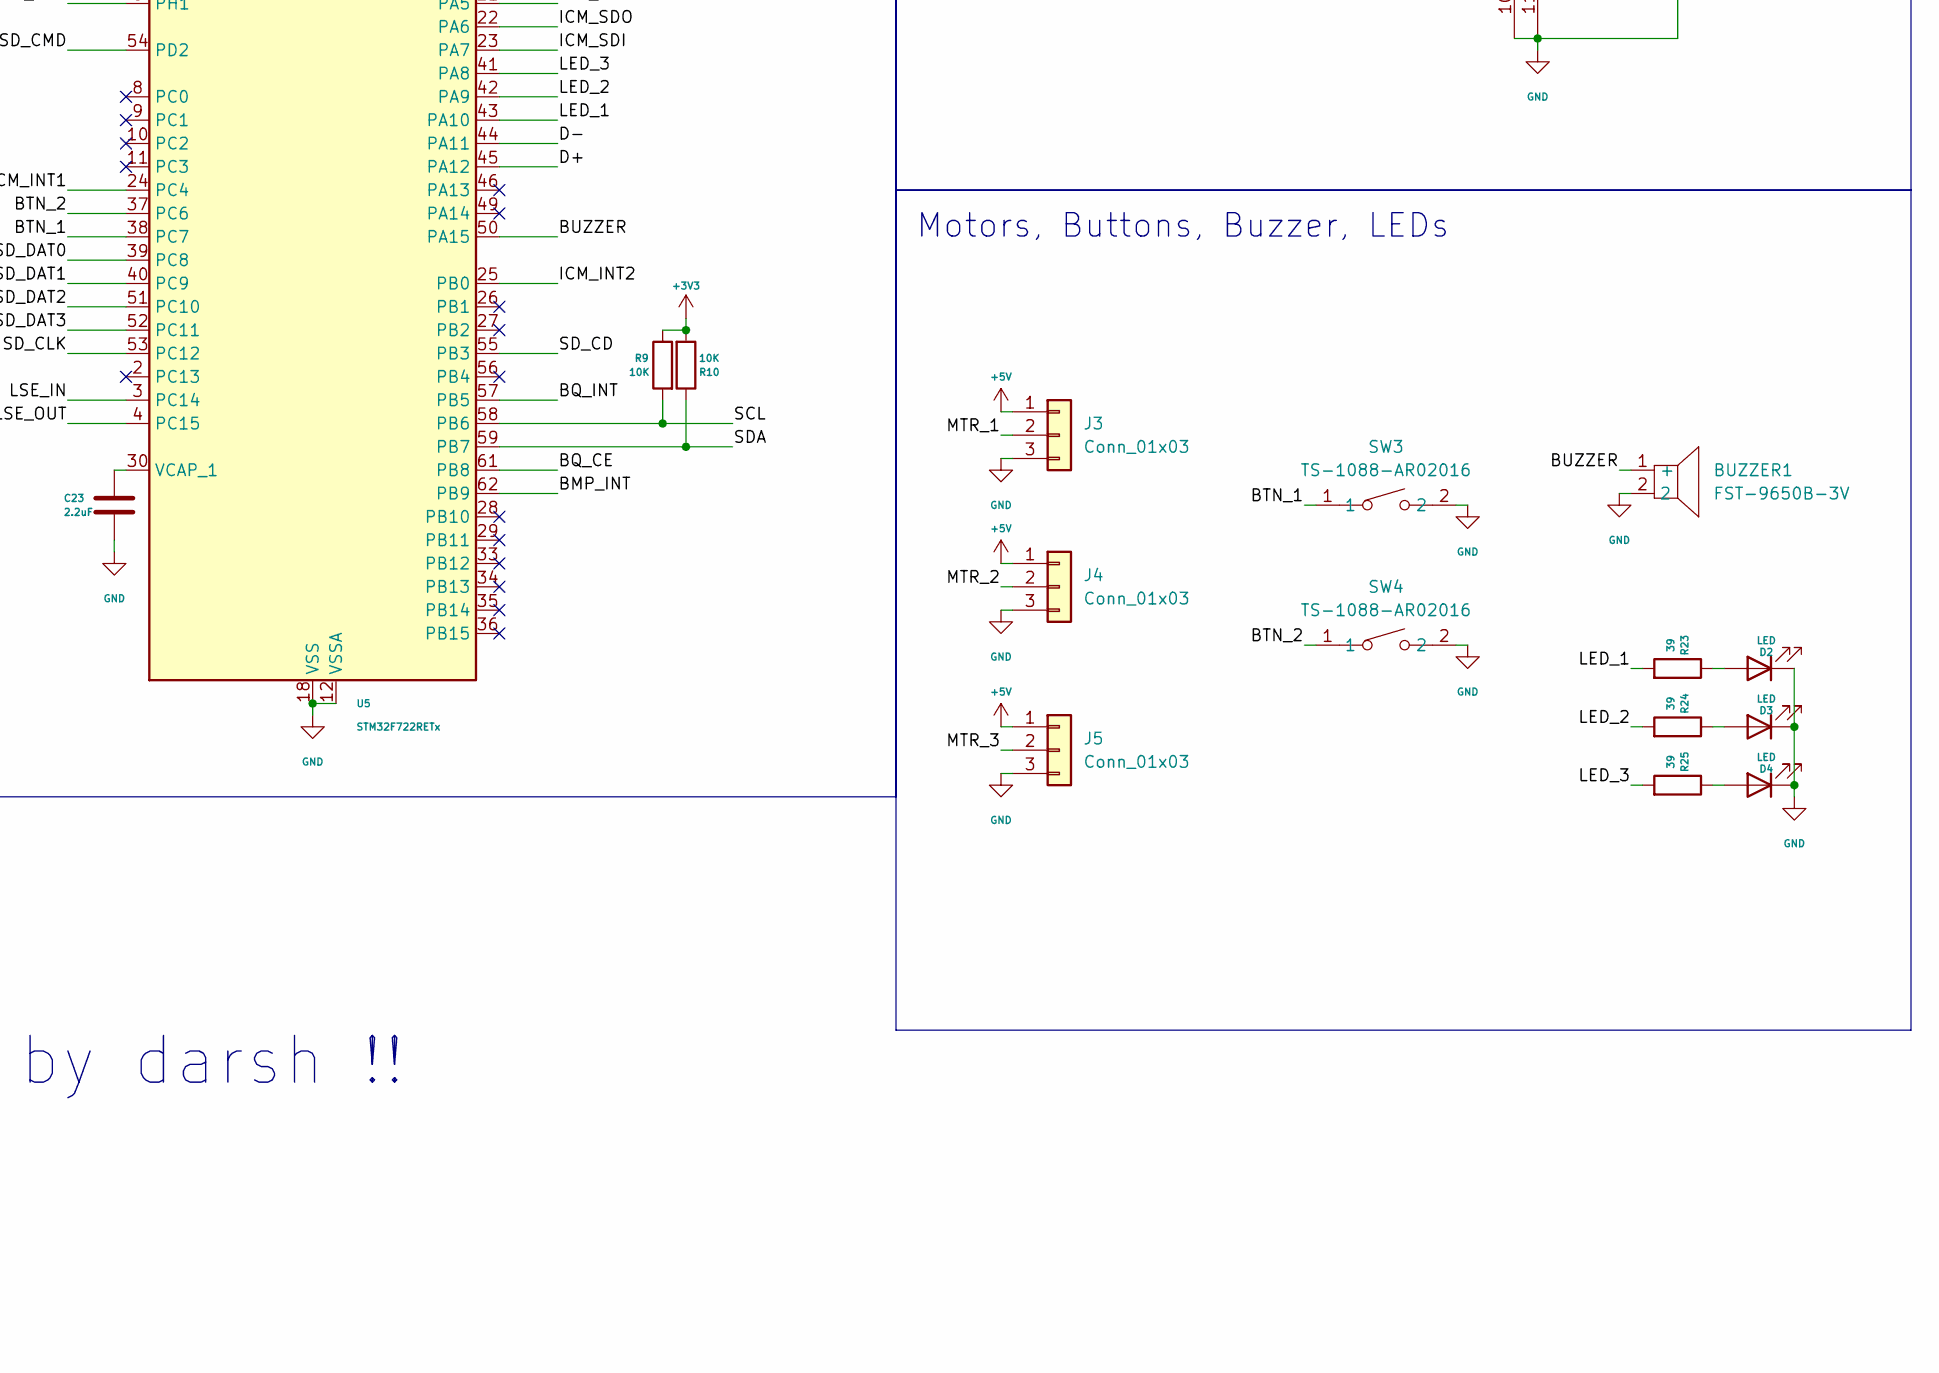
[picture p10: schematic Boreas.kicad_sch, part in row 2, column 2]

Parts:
BUZZER1: FST-9650B-3V; BUZ-SMD_L9.6-W9.6-LS10.0-R; MPN FUET-9650B-3V; LCSC Part C391032
C1, C30, C31, C32: 1uF; C_0402_1005Metric
C2, C4, C5, C7, C8, C9, C10, C33: 10uF; C_0603_1608Metric
C3: 44uF; C_0805_2012Metric
C6: 47nF; C_0402_1005Metric
C11, C12, C14, C17, C18: 22uF; C_0805_2012Metric
C13, C16, C19, C20, C21, C22, C24, C25, C26, C27, C28, C29, C38, C40: 0.1uF; C_0402_1005Metric
C15, C23: 2.2uF; C_0402_1005Metric
C34, C35: 20pF; C_0402_1005Metric
C36, C37: 6.8pF; C_0402_1005Metric
C39: 4.7uF; C_0603_1608Metric
Card1: TF-01A; TF-SMD_TF-01A; MPN TF-01A; LCSC Part C91145
D1, D2, D3, D4: LED; LED_0603_1608Metric
J1: USB_C_Receptacle_USB2.0_16P; USB_C_Receptacle_HRO_TYPE-C-31-M-12
J2: Screw_Terminal_01x02; TerminalBlock_Xinya_XY308-2.54-2P_1x02_P2.54mm_Horizontal
J3, J4, J5: Conn_01x03; PinHeader_1x03_P2.54mm_Vertical
L1: XFL4020-152MEC; IND-SMD_L4.0-W4.0-A; MPN XFL4020-152MEC; LCSC Part C3033018
L2: YHNR3015-5R6M; IND-SMD_L3.0-W3.0; MPN YHNR3015-5R6M; LCSC Part C18236327
L4: FCM1608KF-601T03; L0603; MPN FCM1608KF-601T03; LCSC Part C141723
L5: DFE252012F-1R0M=P2; L2520; MPN DFE252012F-1R0M=P2; LCSC Part C435392
R1, R2: 5.1K; R_0402_1005Metric
R3: 383; R_0402_1005Metric
R4, R7, R8, R9, R10, R11, R12, R13, R14, R18, R19, R20, R21, R22: 10K; R_0402_1005Metric
R5: 5.23K; R_0402_1005Metric
R6: 30.1K; R_0402_1005Metric
R15, R16: 100K; R_0402_1005Metric
R17: 22.1K; R_0402_1005Metric
R23, R24, R25: 39; R_0402_1005Metric
SW1, SW2, SW3, SW4: TS-1088-AR02016; SW-SMD_L3.9-W3.0-P4.45; MPN TS-1088-AR02016; LCSC Part C720477
U1: BMP580; LGA-10_L2.0-W2.0-P0.50-TL_BMP580; MPN BMP580; LCSC Part C22391138
U2: BQ25883RGER; VFQFPN-24_L4.0-W4.0-P0.50-BL-EP2.8; MPN BQ25883RGER; LCSC Part C544362
U3: ICM-45686; LGA-14_L3.0-W2.5-P0.50-TL; MPN ICM-45686; LCSC Part C22459454
U4: TPS63070RNMR; VQFN-15_L3.0-W2.5-P0.50-BL; MPN TPS63070RNMR; LCSC Part C109322
U5: STM32F722RETx; LQFP-64_10x10mm_P0.5mm
U6: LMR51430; SOT-23-6
U7: QMC5883P; LGA-16_L3.0-W3.0-P0.50-BL_SQ; MPN QMC5883P; LCSC Part C2847467
X1: X322525MOB4SI; CRYSTAL-SMD_4P-L3.2-W2.5-BL; MPN X322525MOB4SI; LCSC Part C9006
X2: Q13FC1350000400; FC-135R_L3.2-W1.5; MPN Q13FC13500004; LCSC Part C32346

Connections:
+3V3: C17.1, C18.1, C19.1, C20.2, C21.2, C22.2, C24.2, C25.2, C26.2, C27.2, C28.2, C29.2, C30.2, C31.2, C32.2, C33.2, C40.2, Card1.4 (VDD), L2.2, L4.1, R4.1, R8.2, R9.1, R10.2, R11.2, R13.1, R14.2, R16.2, R18.2, R19.2, R20.2, R21.2, SW2.1, U1.1 (VDDIO), U1.10 (VDD), U3.5 (VDDIO), U3.8 (VDD), U5.1 (VBAT), U5.19 (VDD), U5.32 (VDD), U5.48 (VDD), U5.64 (VDD), U7.2 (VDD)
+5V: C10.2, C11.1, C12.1, C14.1, J3.1, J4.1, J5.1, R15.2, U4.5 (FB), U4.7 (Vout), U4.8 (Vout)
+BATT: C5.1, J2.1, U2.13 (BAT), U2.14 (BAT)
/BMP_INT: U1.7 (INT), U5.62 (PB9)
/BOOT: R22.1, SW2.2, U5.60 (BOOT0)
/BQ_CE: U2.3 (~CE), U5.61 (PB8)
/BQ_INT: R11.1, U2.6 (~INT), U5.57 (PB5)
/BQ_PG: R4.2, U2.9 (~PG)
/BTN_1: SW3.1, U5.38 (PC7)
/BTN_2: SW4.1, U5.37 (PC6)
/BTST: C6.1, L5.2, U2.17 (SW), U2.18 (SW)
/BUZZER: BUZZER1.1 (+), U5.50 (PA15)
/D+: J1.A6 (D+), J1.B6 (D+), U5.45 (PA12)
/D-: J1.A7 (D-), J1.B7 (D-), U5.44 (PA11)
/HSE_IN: C35.2, U5.5 (PH0), X1.1 (OSC1)
/HSE_OUT: C34.2, U5.6 (PH1), X1.3 (OSC2)
/ICM_CS: U3.12 (AP_CS), U5.20 (PA4)
/ICM_INT1: U3.4 (INT1/INT), U5.24 (PC4)
/ICM_INT2: U3.9 (INT2/FSYNC/CLKIN), U5.25 (PB0)
/ICM_SCK: U3.13 (AP_SCL/AP_SCLK), U5.21 (PA5)
/ICM_SDI: U3.14 (AP_SDA/AP_SDIO/AP_SDI), U5.23 (PA7)
/ICM_SDO: U3.1 (AP_SDO/AP_AD0), U5.22 (PA6)
/LED_1: R23.2, U5.43 (PA10)
/LED_2: R24.2, U5.42 (PA9)
/LED_3: R25.2, U5.41 (PA8)
/LSE_IN: C36.2, U5.3 (PC14), X2.1
/LSE_OUT: C37.1, U5.4 (PC15), X2.2
/MTR_1: J3.2, U5.14 (PA0)
/MTR_2: J4.2, U5.15 (PA1)
/MTR_3: J5.2, U5.16 (PA2)
/RST: C38.2, SW1.2, U5.7 (NRST)
/SCL: R9.2, U1.2 (SCK), U2.5 (SCL), U5.58 (PB6), U7.1 (SCK)
/SDA: R10.1, U1.4 (SDI), U2.4 (SDA), U5.59 (PB7), U7.16 (SDA)
/SD_CD: Card1.9 (CD), U5.55 (PB3)
/SD_CLK: Card1.5 (CLK(SCLK)), R21.1, U5.53 (PC12)
/SD_CMD: Card1.3 (CMD(DI)), R20.1, U5.54 (PD2)
/SD_DAT0: Card1.7 (DAT0(D0)), R13.2, U5.39 (PC8)
/SD_DAT1: Card1.8 (DAT1(RSV)), R14.1, U5.40 (PC9)
/SD_DAT2: Card1.1 (DAT2(RSV)), R18.1, U5.51 (PC10)
/SD_DAT3: Card1.2 (CDDAT3(CS)), R19.1, U5.52 (PC11)
GND: BUZZER1.2, C1.2, C2.2, C3.1, C4.2, C5.2, C7.2, C8.2, C9.2, C10.1, C11.2, C12.2, C13.2, C14.2, C15.2, C17.2, C18.2, C19.2, C20.1, C21.1, C22.1, C23.2, C24.1, C25.1, C26.1, C27.1, C28.1, C29.1, C30.1, C31.1, C32.1, C33.1, C34.1, C35.1, C36.1, C37.2, C38.1, C39.1, C40.1, Card1.6 (VSS), Card1.10 (GND), Card1.11 (GND), Card1.12 (GND), Card1.13 (GND), D2.1 (K), D3.1 (K), D4.1 (K), J1.A1 (GND), J1.A12 (GND), J1.B1 (GND), J1.B12 (GND), J1.S1 (SHIELD), J2.2, J3.3, J4.3, J5.3, R1.1, R2.1, R3.2, R6.1, R7.1, R17.1, R22.2, SW1.1, SW3.2, SW4.2, U1.3 (VSS), U1.5 (SDO), U1.6 (CSB), U1.8 (VSS), U1.9 (VSS), U2.19 (GND), U2.20 (GND), U2.25 (EP), U3.6 (GND), U4.4 (GND), U4.6 (FB2), U4.10 (PGND), U4.15 (Vsel), U5.12 (VSSA), U5.18 (VSS), U5.31 (VSS), U5.47 (VSS), U5.63 (VSS), U6.1 (GND), U7.9 (GND), U7.11 (GND), X1.2 (GND), X1.4 (GND)
unnamed: C2.1, L5.1, U2.21 (PMID), U2.22 (PMID)
unnamed: D1.2 (A), R8.1
unnamed: D1.1 (K), U2.2 (STAT)
unnamed: D2.2 (A), R23.1
unnamed: D3.2 (A), R24.1
unnamed: D4.2 (A), R25.1
unnamed: J1.A5 (CC1), R2.2
unnamed: J1.B5 (CC2), R1.2
unnamed: C6.2, U2.12 (BTST)
unnamed: R3.1, U2.8 (ILIM)
unnamed: R5.1, R6.2, R7.2, U2.7 (TS)
unnamed: R12.1, U4.1 (PS/SYNC), U4.14 (EN)
unnamed: L1.2, U4.11 (L1)
unnamed: L1.1, U4.9 (L2)
unnamed: R15.1, U4.2 (PG)
unnamed: C13.1, U4.3 (Vaux)
unnamed: C23.1, U5.30 (VCAP_1)
unnamed: L4.2, U5.13 (VDDA)
unnamed: C16.1, U6.6 (CB)
unnamed: R16.1, R17.2, U6.4 (FB)
unnamed: C16.2, L2.1, U6.2 (SW)
unnamed: C39.2, U7.10 (C1)
VBUS: C1.1, J1.A4 (VBUS), J1.A9 (VBUS), J1.B4 (VBUS), J1.B9 (VBUS), U2.23 (VBUS)
VREGN: C4.1, R5.2, U2.11 (REGN)
VSYS: C3.2, C7.1, C8.1, C9.1, C15.1, R12.2, U2.15 (SYS), U2.16 (SYS), U4.12 (Vin), U4.13 (Vin), U6.3 (VIN), U6.5 (EN)

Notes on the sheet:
Magnetometer
Motors, Buttons, Buzzer, LEDs
SD Card
3.3V Converter
USB-C
Barometer
5V Converter
Battery Charging
IMU
by darsh !!
STM32, Crystals, Boot Buttons

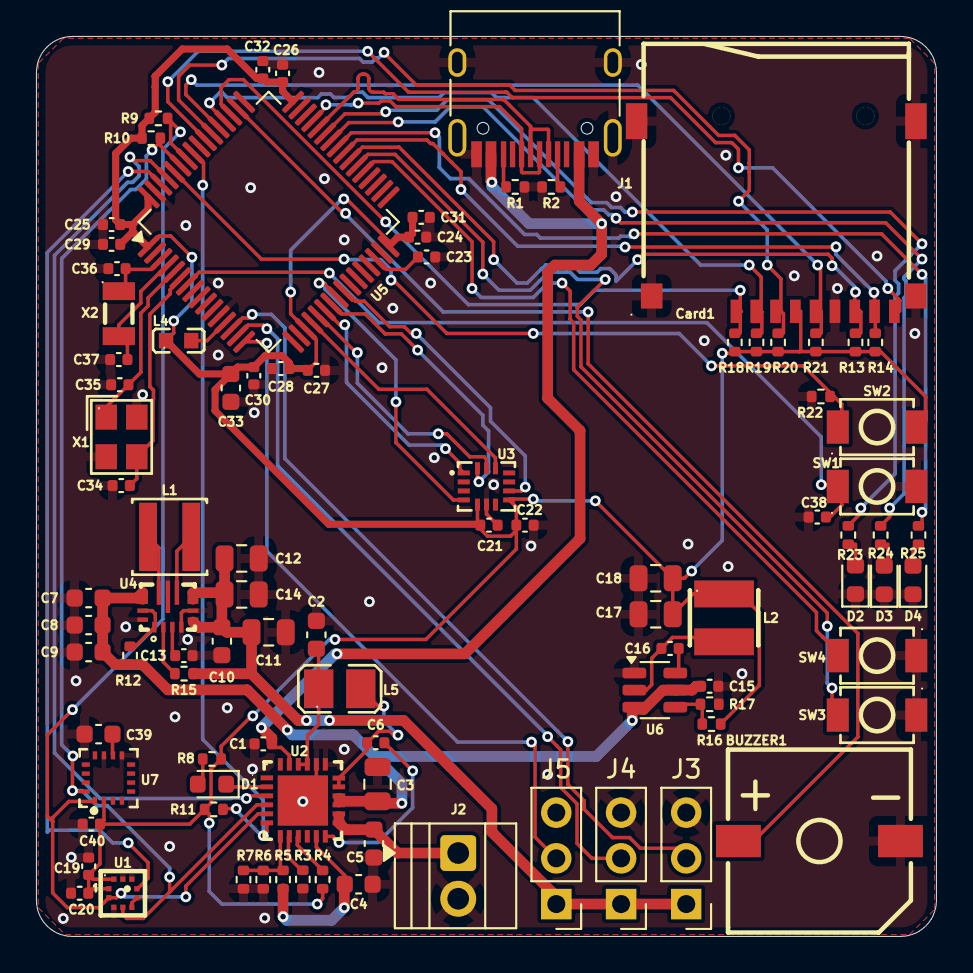
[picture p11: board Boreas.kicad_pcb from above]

Board: 2 copper layers, 50.0 x 50.0 mm, 93 parts (0 on the bottom side), 66 nets.

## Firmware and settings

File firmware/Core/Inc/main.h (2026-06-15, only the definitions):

#define ICM_INT1_Pin GPIO_PIN_4
#define ICM_INT1_GPIO_Port GPIOC
#define ICM_INT2_Pin GPIO_PIN_0
#define ICM_INT2_GPIO_Port GPIOB
#define BUZZER_Pin GPIO_PIN_15
#define BUZZER_GPIO_Port GPIOB
#define BTN_2_Pin GPIO_PIN_6
#define BTN_2_GPIO_Port GPIOC
#define BTN_1_Pin GPIO_PIN_7
#define BTN_1_GPIO_Port GPIOC
#define LED_3_Pin GPIO_PIN_8
#define LED_3_GPIO_Port GPIOA
#define LED_2_Pin GPIO_PIN_9
#define LED_2_GPIO_Port GPIOA
#define LED_1_Pin GPIO_PIN_10
#define LED_1_GPIO_Port GPIOA
#define SD_CS_Pin GPIO_PIN_3
#define SD_CS_GPIO_Port GPIOB
#define BQ_INT_Pin GPIO_PIN_5
#define BQ_INT_GPIO_Port GPIOB
#define BQ_CE_Pin GPIO_PIN_8
#define BQ_CE_GPIO_Port GPIOB
#define BMP_INT_Pin GPIO_PIN_9
#define BMP_INT_GPIO_Port GPIOB

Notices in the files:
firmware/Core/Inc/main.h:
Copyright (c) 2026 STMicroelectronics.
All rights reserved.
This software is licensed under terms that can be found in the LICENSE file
